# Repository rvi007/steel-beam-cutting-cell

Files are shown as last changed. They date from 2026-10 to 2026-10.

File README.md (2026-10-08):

# BEAM CELL

### Robotic cutting of UK structural steel

**Two robot arms on an overhead gantry (12 m or 20 m long) that cut beams to size: bolt holes, slots, notches,
mitres and cut-to-length. Drawings in, finished beams out.**

By **Ravi Mahadeva** · UK codes · runs on an NVIDIA Jetson Orin Nano · opens in any web browser

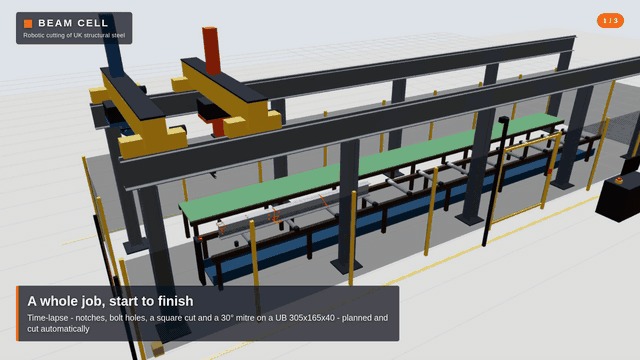
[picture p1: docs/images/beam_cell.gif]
BEAM CELL cutting a beam


▶ **[Watch the 30-second video](docs/video/beam_cell_30s.mp4)**

> 🤝 **Looking for collaborators and sponsors** - steel fabricators, engineers, robotics and automation
> people, and anyone who can help with parts, workshop space or test steel:
> **[get in touch](https://github.com/rvi007/steel-beam-cutting-cell/issues/new/choose)**.
> You're welcome to read everything here; using, building on or selling the code or the design needs
> written permission - see [LICENSE](LICENSE).

---

## What it does

Two robot "hands" hang from an overhead gantry above a 12-metre roller bed:

| | The **Cutter** (orange) | The **Handler** (blue) |
|---|---|---|
| Tool | plasma torch | electromagnet |
| Job | bolt holes, slots, openings, notches (copes), mitres, cut-to-length | holds each part while it is cut free, then carries it to the outfeed table |

You give it parts, as **NC1 files** from Tekla, Advance Steel or SDS2, or drawn on screen. It then:

1. **checks every part against the UK codes**, and tells you what is wrong and why,
2. **fits the parts onto stock bars** to waste as little steel as possible,
3. **plans every move of both arms** and checks they never collide,
4. **plays the whole job in 3D**, with a real safety system around it.

Or use **manual cut**: click on the beam to put a hole or a cut exactly there.

Everything in the 3D view is real CAD: the same solids are in the STEP files in `cad/`. There is
also a **1:10 desk-top prototype**, about £1,150 to build, with a shopping list and an assembly drawing.

## Start it

On the Jetson (or any Linux PC or Mac):

```
git clone https://github.com/rvi007/steel-beam-cutting-cell.git
cd steel-beam-cutting-cell
sudo apt install python3-numpy python3-opencv     # once; OpenCV is only needed for the camera
./start.sh
```

Then open **http://localhost:8080** in a web browser. From a phone, tablet or laptop on the same Wi-Fi,
use the address the terminal prints (for example `http://192.168.1.20:8080`).

**Every time after that:** `cd steel-beam-cutting-cell`, then `git pull` (to get the latest version), then `./start.sh`.

**Start it automatically when the Jetson boots:** see [docs/JETSON_SETUP.md](docs/JETSON_SETUP.md).

**Something not working?** Run `python3 -m beamcell.doctor`. It checks everything and tells you what to fix.

## A 5-minute tour

1. **Safety tab**: press **Reset**, tick the pre-start checklist and confirm. Like a real machine, nothing moves until you do.
2. **Machine tab**: example parts are already loaded. Press **Plan this bar**, then **Run**.
   Press **Follow Cutter** to watch the holes and notches being cut, and **Follow Handler** to watch a finished beam carried away.
   Point at anything in 3D to see what it is.
3. **Parts tab**: drag in NC1 files from Tekla, or pick *Add an example*. Every face is drawn,
   with its UK code checks. Click a part to edit it, for example to add a bolt group or a notch.
4. **Manual cut** (top left of the Machine tab): pick a section and a length, click on the beam to put a hole there,
   press **+ Cut** to cut it, then **Plan these cuts** and **Run**.
5. **E-STOP** (or the Esc key) while it runs: everything stops. Release it, press Reset, then Start to carry on.
6. When a job finishes, the **Job finished** window asks what next: next bar, run again or **Delete this job**.
   **Job history & saved jobs** (Machine tab) lists every job that ran, whether it ran **clean** or was stopped
   (each E-stop, gate or camera stop with its time), each with a **Delete** button.
7. **Prototype tab**: the 1:10 prototype in 3D. Every part is numbered, matching the shopping list. Click a part to see what it is and where to buy it.
8. **Camera tab**: start the camera and walk towards the machine. It slows down when you get close and stops when you get too close.
9. **Plasma tab**: plasma doesn't always cut the same, so try settings on a test piece, then save the ones that work, named after the beam.
   Next time that beam is cut, the Machine tab uses them automatically.
10. **Reports** (top right): every stop during a job saves a problem report. Add a note and press **Send to developer**.
11. **Machine size** (Machine tab): 12 m or 20 m long, 3 m wide. Stock bars up to 20 m; the 3D model, planning and checks follow.
12. **Bar check at Start**: after the safety checks, the Cutter measures the bar and checks it against the job (section, thicknesses,
   length, every hole, holes already in the bar). If it doesn't match, the job doesn't start and a window says why.
   Try it: Sensors tab, *Bar on the bed*, pick "a bar too short", then press Run. When the bar matches, a window shows the
   program next to what was measured on the cutting area (web and flange), then cutting starts.
13. **Power cut or stop in the middle of a job**: progress is saved to disk every second. When the app starts again a window
    says when, why and where it stopped and what is done. *Carry on* skips what is done, redoes the interrupted operation from
    its start, re-measures the bar and checks the cuts already made (scan back) before anything moves; a green arrow and a
    banner show where it restarts.
14. **Loading and unloading without entering the cell**: bars are put down by forklift / side loader (or beam dollies) on the
    infeed cross-transfer rack outside, and a driven infeed conveyor takes them in through the light-curtain opening. After a
    job the outfeed cross-transfer carries the finished parts out through the back fence (perimeter light grid with muting)
    onto a buffer rack beside a marked forklift aisle; short parts go in a stillage for the pallet truck.
15. **Sensors tab**: every sensor (two cameras, bar finding, torch, magnet, safety), the **bar check**, the **plasma settings**,
   and what each hand does for every stop. Press **Simulate** on "load slipping" or "object on the bed" and watch it react.

<details>
<summary><b>Camera not working?</b></summary>

1. Run `python3 -m beamcell.doctor`. The **Cameras** line lists every camera Linux can see and says what's wrong.
2. In the app's Camera tab, leave **Auto** selected, or pick the camera from the list.
3. Common fixes:
   - **No camera found at all:** plug the USB camera straight into the Jetson (not into an unpowered hub), or reseat the CSI ribbon cable (blue side towards the latch), then reboot.
   - **"not in the video group":** run `sudo usermod -aG video $USER`, then log out and back in.
   - **CSI ribbon camera:** it needs the Jetson's own OpenCV (`sudo apt install python3-opencv`), not `pip install opencv-python`. Test the camera with `nvgstcapture-1.0`.
   - **Camera busy:** close any other program that is using it (Cheese, a browser tab).
</details>

## Documents

| Read this | To learn about |
|---|---|
| [Safety](docs/SAFETY.md) | **stops, UK law and standards, risk assessment, E-stop wiring** |
| [Sensors](docs/SENSORS.md) | **the two cameras, how the beam is found and measured, what each hand does when something goes wrong, the standards** |
| [Plasma](docs/PLASMA.md) | how the torch finds the steel and holds its height; settings for each kind of cut |
| [How the machine works](docs/MACHINE.md) | the layout, how a bar is cut, and a map of the code |
| [UK codes](docs/UK_CODES.md) | every UK rule it checks, and where each one comes from |
| [NC1 files](docs/NC1_FILES.md) | getting parts out of Tekla: what is read, faces and coordinates |
| [Steel frame in Tekla](docs/TEKLA.md) | the cell's structural steelwork as IFC for Tekla: import, marks, cut list, what the engineer must design |
| [The 1:10 prototype](docs/PROTOTYPE.md) | **what to buy (about £1,150), how to build it, safety wiring** |
| [Shopping list (PDF)](docs/Prototype_Shopping_List.pdf) | every part with its price and a link to buy it, to print out |
| [Assembly drawing (PDF)](docs/Prototype_Assembly.pdf) | every part numbered and shown where it goes |
| [Jetson setup](docs/JETSON_SETUP.md) | running on the Orin: start at boot, full-screen mode, camera, YOLO, memory |
| [The AI advisor](docs/ASSISTANT.md) | "what's happening" in plain English, and the optional AI advisor |
| [A scale model](docs/SCALE_MODEL.md) | a static display model at 1:20 or 1:100 |
| [Jetson specs](docs/JETSON_SPECS.md) | the Orin's hardware and software |
| [How the code works](docs/HOW_IT_WORKS.md) | **a guided tour: which file does what, how the screen and the engine work together, the journey of a job** |
| [For developers](docs/DEVELOPMENT.md) | how the code fits together, and the rules for changing it |

## Honest limits

- **It is a simulation and a planner, not yet a machine controller.** It doesn't drive motors yet.
  The prototype guide explains what's needed for that.
- **Check NC1 files against their drawings.** The face conventions follow the DSTV standard as
  usually exported. Check one of your own Tekla parts against its drawing (see [NC1 files](docs/NC1_FILES.md)).
- **The safety functions are software.** They behave like a real safety system, but a real machine needs
  them in certified safety hardware, and a camera with AI is never a safety device on its own (see [Safety](docs/SAFETY.md)).
- **Section sizes come from published Blue Book data.** Check them against current mill data before real fabrication.

<details>
<summary><b>For developers: folders, tests, CAD and the video</b></summary>

### What's in each folder

```
steel-beam-cutting-cell/
├── start.sh              starts the app (./start.sh --camera 0 starts it with the camera on)
├── config/cell.toml      all the settings: safety, camera zones, GPIO wiring, AI advisor, port
├── beamcell/             the engine (Python)
│   ├── server.py         web server and the API the browser talks to
│   ├── safety.py         safety controller: E-stop, interlocks, modes, reset/start, watchdogs
│   ├── history.py        job history (jobs/history.json)
│   ├── plasma_presets.py saved plasma settings that worked (plasma_settings/)
│   ├── reports.py        problem reports for the developer after every stop (reports/)
│   ├── gpio_inputs.py    real E-stop / gate / light curtain / reset buttons on the Jetson's pins
│   ├── assistant.py      "what's happening" in plain English + the optional AI advisor
│   ├── doctor.py         system check: python3 -m beamcell.doctor
│   ├── sections.py       UK section library and exact cross-sections (data/uk_sections.json)
│   ├── uk_codes.py       UK code values: hole sizes, edge distances, grades
│   ├── parts.py          parts, notches, mitres, the code checks, nesting on bars
│   ├── nc1.py            reads and writes DSTV NC1 files
│   ├── arm.py, machine.py   the 6-axis arms and the cell's sizes
│   ├── planner.py        plans every move of both hands for a bar
│   ├── manual.py         manual cutting
│   ├── collisions.py     checks the arms never touch the steel
│   ├── cad.py            makes the CAD: STEP files and the 3D view's models (needs CadQuery)
│   └── vision.py         camera + YOLO person detection + safety zones
├── web/                  the app in the browser (index.html, css/, js/, models/, vendor/three.js)
├── cad/                  STEP files: the whole cell, the 1:10 prototype, every example part
├── examples/nc1/         example NC1 files of typical UK parts
├── docs/                 the documents above, images, video, PDFs
├── tools/                makes the example files, PDFs, assembly pictures and the video
├── deploy/               start-at-boot service for the Jetson
├── tests/                automatic tests (GitHub runs them on every push)
├── models/               put YOLO .onnx models here (see docs/JETSON_SETUP.md)
└── jobs/, logs/, plasma_settings/, reports/
                          your saved jobs, job history, safety log, plasma settings and problem reports (not in git)
```

### Tests

```
python3 -m unittest discover -s tests -t .     # about 1 minute
python3 tests/sweep_sections.py                # every UK section, about 4 minutes
```
GitHub runs the tests on every push: with the Orin's versions (Python 3.12, numpy 1.26.4,
OpenCV 4.6) and the latest ones, plus a browser test of the whole app and a CAD build.

### Make the CAD again (after changing the machine)

On a PC (CadQuery is big; the Jetson doesn't need it because the files are already in the repo):
```
pip install cadquery
python3 -m beamcell.cad                 # everything: parts, the cell, the prototype
python3 -m beamcell.cad parts my.nc1    # STEP solids of your own NC1 parts
```

### Make the video again

```
python3 -c "import beamcell.server as s; s.SAFETY.cfg['heartbeat_timeout_s'] = 600; s.main(['--port', '8099'])" &
node tools/make_video.mjs http://localhost:8099 docs/video/beam_cell_30s.mp4
```
</details>

## Author and licence

**Ravi Mahadeva**: design, development and the prototype.

© 2026 Ravi Mahadeva. All rights reserved. See [LICENSE](LICENSE). The UK section data comes
from the `steelsnakes` package (GPL-2.0), and three.js is MIT-licensed (`web/vendor/LICENSE-three.txt`).

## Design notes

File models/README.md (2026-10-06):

# YOLO models

Put `yolo11n.onnx` here, then build the GPU engine on the Jetson: `tools/make_trt_engine.sh`
(it makes `yolo11n.engine`). Pick "YOLO on the GPU" in the Camera tab.
See docs/JETSON_SETUP.md, "Person and object detection (YOLO) - on the GPU".
Model files aren't kept in git (size, and Ultralytics models are AGPL-3.0).

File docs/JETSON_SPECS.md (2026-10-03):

# Jetson specs (the user's local machine)

Read from the board on 2026-10-03. This is where the Arduino, servo, knob and 3D
windows run. Cloud sessions can't reach it, so write code that fits these limits.

## Hardware
| Part | Spec |
|---|---|
| Board | NVIDIA Jetson Orin Nano Developer Kit **Super** |
| CPU | 6-core Arm Cortex-A78AE, up to 1.73 GHz (aarch64) |
| GPU | NVIDIA Ampere, up to 1.02 GHz in Super mode |
| RAM | **4 GB** (3.4 GB usable), shared by CPU and GPU |
| Swap | 1.7 GB zram (compressed RAM) |
| Power mode | `MAXN_SUPER` (fastest) |

The 3.4 GB of usable RAM points to the 4 GB Orin Nano. NVIDIA's spec sheet for that
model lists 512 CUDA cores, 16 tensor cores and about 34 TOPS in Super mode
(spec-sheet figures, not measured on this board).

## Storage
| Item | Detail |
|---|---|
| Drive | 256 GB NVMe SSD, EDILOCA EN605 (238.5 GB usable) |
| Root `/` | `nvme0n1p1`, ext4, 233 GB: **30 GB used, 191 GB free (14%)** |
| `/boot/efi` | `nvme0n1p10`, vfat, 63 MB |
| Other partitions | 13 small NVIDIA boot/firmware partitions (under 0.5 GB each), no filesystem mounted |
| Space use | `/usr` 21 GB, `/opt` 4.5 GB, `/home/ravi` 2.8 GB, `/var` 1.5 GB |
| SD card | None |

## Software
| Item | Version |
|---|---|
| JetPack | 7.2.1 (Jetson Linux R39.2.1) |
| OS | Ubuntu 24.04.4 LTS, kernel 6.8.12-tegra |
| CUDA | 13.2 |
| TensorRT | 10.16 |
| Python | 3.12.3 |
| Python libs | numpy 1.26.4, matplotlib 3.6.3 (TkAgg), scipy 1.11.4, OpenCV 4.6.0, pyserial 3.5 |
| PyTorch | Not installed |
| arduino-cli | `~/.local/bin/arduino-cli`, board `arduino:avr:uno` |

## Connections
- Internet: Wi-Fi through a phone hotspot (`172.20.10.x`). **Avoid big downloads.**
- Ethernet: not connected.
- Arduino UNO: USB on `/dev/ttyACM0` (group `dialout`).

## Limits to design around
- **Memory is very tight.** When checked, only about 365 MB of RAM was free and the
  1.7 GB swap was full, with the desktop and a 3D window open. Run one GUI program at a
  time and keep scripts light: no big arrays, no heavy plotting loops.
- Only numpy, matplotlib, scipy, OpenCV and pyserial are available. Don't add
  dependencies that need `pip install`.
- matplotlib 3D redraws are the slowest part. The control loops run at about 20 Hz
  (`plt.pause(0.05)`), so don't add work that slows them down.

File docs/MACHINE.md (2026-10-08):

# The machine and how a job runs

## Layout

```
   Y (width 3 m)            safety fence all round, gate + light curtain at the front
   ^      runway beams (UB on UC columns), rails at 3.4 m
   |  ==================================================================
   |   outfeed table (green)    y = +0.85   finished parts are put down on it
   |
   |   stock bar on rollers     y = -0.50   up to 12 m, rollers every 1 m, scrap tray underneath
   |  ==================================================================
   +----------------------------------------------------------------------> X (12 m)
        HANDLER bridge (blue) ->                     <- CUTTER bridge (orange)
        parks at x = -1.1                                parks at x = 13.1
```

| | Cutter (orange) | Handler (blue) |
|---|---|---|
| Job | plasma torch: holes, slots, openings, notches, end cuts, cut-off | magnet: holds each part while it's cut free, puts it on the outfeed table |
| Gantry axes | X bridge 1.0 m/s, Y carriage 0.8 m/s, Z column 0.5 m/s | same |
| Arm | 6 axes, UR5 geometry (upper arm 425 mm), hung upside down | 6 axes, 1.3x bigger |
| Tool | 400 mm plasma torch (long, to reach under wide flanges) | magnet pad, 500 kg |
| Total | 9 axes | 9 axes |

Both bridges share the rails: the Handler works on the low-X side, the Cutter on the high-X
side, and the planner keeps them at least **1 m** apart at every moment. Both arms work
**elbow up** (like real ceiling-mounted robots): the whole arm stays above the tool tip.

## How sections lie on the bed

| Section | Lies | Torch passes for a cut |
|---|---|---|
| UB / UC / UBP | web upright, centred | top flange straight down; web from the +Y side (between the flanges); bottom flange with the torch tilted 45° from each side of the web |
| PFC | web upright on the +Y side, flanges pointing -Y | top flange down; web from outside; bottom flange tilted 45° from the open side |
| Angles | longer leg upright on the +Y side, other leg flat | upright leg from the side; heel corner tilted 45°; flat leg straight down |
| Hollow | not cut (needs a chuck) | - |

Holes are cut straight through their plate: top flange from above, web from the side, the
flat leg of an angle from above. Bottom-flange holes on I sections and channels can't be
reached.

## How a bar is cut

1. Parts are **nested** on the bar: 10 mm trimmed off the rough mill end, then part after
   part. Two square ends share one cut; a notched or mitred end gets a 20 mm gap.
2. For each part, from X = 0 upwards:
   1. the start cut, unless it shares the previous part's cut-off - the offcut falls between the
      rollers into the scrap tray;
   2. holes, slots and openings **in order along the bar**, one bolt group at a time, top hole
      first - never jumping back and forth;
   3. the Cutter goes to the cut-off and waits; the **Handler** comes in and puts its magnet on the part;
   4. the cut-off, face by face;
   5. the Handler lifts the part 250 mm, carries it to the outfeed table and puts it down,
      while the Cutter starts on the next part.
3. A last part that reaches the end of the bar needs no cut-off: the Cutter moves out of the
   way and the Handler takes it. Anything left over is the remnant and stays on the bed.

**Gravity:** nothing floats. The bar rests on rollers (every 1 m, top at 0.9 m). A loose piece
stays on the bed only if it spans two rollers - otherwise it would tip, so short offcuts and a
short remnant fall (time from g = 9.81 m/s²) into the scrap tray, and short, tall slices tip over
flat. Carried parts are put down exactly on the outfeed table. `tests/test_planner.py` checks it.

**Holes are where the drawing says.** The planner never moves a hole: x and y come from the NC1
file or the part editor. New bolt groups in the editor (and the example files) sit on the
centre line of the web that's left (below any notch); a **centre** button puts any hole there.

## Manual cutting

Machine tab, **Manual cut**: pick a section and bar length, then add holes, cuts (square or
mitred in the web) and notches - or click on the web / top flange in the 3D view. The cuts
split the bar into pieces: each piece is carried to the outfeed table, pieces under 150 mm fall
into the scrap tray, the rest stays on the rollers. Same UK checks, same planner and collision
check, same safety rules (`beamcell/manual.py`).

Long cuts (over 150 mm - webs of deep beams, flanges) move the gantry with the torch, as a
real machine's coordinated axes do; short ones (holes) use the arm alone.

## Safety, by construction and by checking

- **Bridges**: a move that would bring them within 1 m waits for the other hand, or makes it back off.
- **Travel**: long moves lift the column to 3.0 m, travel, then come down.
- **Torch approach**: the torch comes in and leaves along its own axis, from a point outside the section.
- **Collision check** (`beamcell/collisions.py`): the whole plan is replayed every 0.4 s and every
  arm link and tool is checked against the steel (each plate following its real outline, so
  notches count; offcuts until they drop; carried parts where they are) and the bed.
- **Safety controller** (`beamcell/safety.py`): E-stop, gate, light curtain, extraction, camera
  zones, modes, watchdogs - every stop latches; Reset then Start (see `SAFETY.md`).

`tests/sweep_sections.py` plans a typical part on **every one of the 267 cuttable UK
sections** (from a 20x20 angle to UB 1016x305x584) and checks all of the above: 0 problems.

## Timing

Plasma speeds follow typical 130 A values: 50 mm/s up to 6 mm thick down to 10 mm/s over
20 mm; tilted cuts count as 1.4x the thickness. Each pierce takes 0.6 s. A typical bar of two
5.2 m notched secondary beams takes about 7.5 minutes.

## Code map

| File | What it does |
|---|---|
| `beamcell/sections.py` | UK section library, exact outlines with radii, plates and DSTV faces |
| `beamcell/uk_codes.py` | BS EN 1090-2 / BS EN 1993-1-8 / SCI values |
| `beamcell/parts.py` | parts, face outlines (notches, mitres), cut chains, UK checks, nesting onto bars |
| `beamcell/nc1.py` | reads and writes DSTV NC1 files |
| `beamcell/arm.py` | 6-axis arm kinematics, IK for any tool direction |
| `beamcell/machine.py` | the cell's sizes, the two hands, comfortable elbow-up poses |
| `beamcell/planner.py` | turns a bar into timed tracks for both hands, and where loose pieces fall |
| `beamcell/manual.py` | manual cutting: the operator's cuts become pieces and a plan |
| `beamcell/cad.py` | the CAD model: STEP files and `web/models/*.glb` (CadQuery, on a PC) |
| `beamcell/collisions.py` | replays a plan and checks arms against the steel |
| `beamcell/vision.py` | camera, YOLO / HOG person detection, warning + danger zones |
| `beamcell/safety.py` | safety controller: E-stop, interlocks, modes, reset/start, watchdogs, ISO 13855 distance |
| `beamcell/gpio_inputs.py` | optional wired E-stop / gate / curtain / reset on the Jetson's pins (fail-safe) |
| `beamcell/assistant.py` | plain-English situation + optional AI advisor |
| `beamcell/doctor.py` | system check and setup plan |
| `beamcell/config.py` | reads `config/cell.toml` |
| `beamcell/server.py` | web server and JSON API |
| `web/js/scene.js` | the 3D cell: loads the CAD model (GLB) and poses the moving bodies with the kinematics; hover labels |
| `web/js/manual.js` | the Manual cut panel, markers and clicking on the steel |
| `web/js/geometry.js` | steel parts plate by plate, with real holes and notches |
| `web/js/app.js` | playback of the plan, the Machine tab |
| `web/js/parts.js` | Parts tab: NC1 import, editor, drawing, checks |
| `web/js/library.js` | Section library and STL export |
| `web/js/camera.js` | Camera tab |

## Next steps (ideas)

1. Read real NC1 files from your Tekla models and compare the drawings (see `NC1_FILES.md`).
2. Train a YOLO model to see the **beam** (its end and position) so the Cutter corrects for
   where the bar really lies.
3. Bevel cuts for weld preparation (the torch is already 6-axis).
4. Drive a 1:10 model's motors from the plan (see `SCALE_MODEL.md`).
5. Two-hand lifting for parts over 500 kg.

## Loading and unloading (material flow)

Nobody walks into the cell to load or unload it. Steel moves in and out on conveyors, and people and forklifts work outside the guard:

| Where | What | Who / what moves it |
|---|---|---|
| **Infeed rack** (outside, infeed end) | chain cross-transfer arms every 2.5 m at bed height; a stop lets one bar at a time onto the conveyor | forklift with a side loader, an overhead crane, or a pallet truck with beam dollies, in the marked loading aisle |
| **Infeed conveyor** (outside, in line with the bed) | driven 101.6 mm rollers every 1 m, chain guard, gearmotor; bridging rollers through the light-curtain opening | the machine: drives the bar in; the pop-up end stop drops while it comes in, then rises and the bar is datumed against it |
| **Outfeed cross-transfer** (inside to outside, back) | chain arms every 1 m (a short part always sits on two), line shaft and gearmotor | the machine, after each job, only when the cell is clear (safety PLC) |
| **Back opening** | perimeter light grid, 4 beams (SICK deTem4 class, Type 4), muting sensors and lamp | lets steel on the transfer through, stops the machine for a person (BS EN IEC 62046, BS EN ISO 13855) |
| **Buffer rack** (outside, back) | the arms continue 1.7 m outside the fence onto legs, with end stops | forklift / side loader picks the parts from the marked unloading aisle |
| **Pallet-truck bay** | stillage on a Euro pallet for short parts and offcuts | hand pallet truck |

A hand pallet truck is right for stillages, not for long beams: a 6-12 m beam needs a side loader, a crane, or two beam
dollies. Aisles are 3.5 m wide and marked (HSG136 workplace transport).

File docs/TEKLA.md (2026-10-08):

# The steel frame in Tekla Structures

This is for the steel detailer. The cell's fabricated structural steelwork is exported as an IFC model
you can bring into Tekla, convert to native parts, connect up, and get drawings and NC1 files from.

| File | What |
|---|---|
| `cad/beam_cell_steel_12m.ifc` | the 12 m machine's frame (IFC2X3, millimetres) |
| `cad/beam_cell_steel_20m.ifc` | the 20 m machine's frame |
| `cad/beam_cell_steel_12m.csv`, `_20m.csv` | cut lists: every mark, then totals by profile, then the grand total |

Made by `python3 -m beamcell.ifc_export` (code in `beamcell/ifc_export.py`, checks in `tests/test_ifc.py`).
Run it again after any change to the machine's sizes in `beamcell/machine.py`.

## Importing into Tekla

The file is **IFC2X3** (Coordination View 2.0 style), which Tekla imports most reliably. There are two ways in.

**1. As a reference model, then convert (recommended).**
1. *Manage > Reference model* (older versions: *File > Insert reference model*), pick the .ifc, insert at 0,0,0, scale 1.
2. Select the reference objects, right-click *Convert IFC objects* (or *Manage > Convert IFC objects*).
3. Tekla makes real beams, columns and plates with the profile, material and position from the file. Check
   the conversion log for anything left as a "brep" - there should be nothing; every member is a simple extrusion.

**2. File > Import > IFC** (older versions and some environments). It makes Tekla parts straight away.
Use this if you don't want a reference model hanging about.

**Profile and material mapping.** Each member's profile name is already in the Tekla UK catalogue format:
`UB457*191*67`, `UC254*254*73`, `RHS120*80*5`, `RHS100*80*5`, `SHS80*80*5`, `SHS100*100*6.3`, `L70*70*7`,
`PL25*500`, `PL20*300`, `FL60*50`, `FL60*30`. It's in three places: the profile (`ProfileName`), the element's
`ObjectType`/`Description`, and the property set. If your environment names something differently (e.g. `EA70*70*7`
rather than `L70*70*7`), add a line to the conversion's profile mapping file (`ProfileConversion.cnv` /
*IFC object conversion > Profile mapping*) rather than editing the model. The material is `S355` throughout: map
it to S355J2 (or S355J2H for the hollow sections) in the material mapping if your catalogue wants the sub-grade.

After converting, run *Clash check* against your connections and *Numbering* - Tekla will renumber; the marks
below are only for referring back to this model and the cut list.

## Coordinates

- Origin: the **bar datum** - the face of the bar end stop on the bed's centre line, at finished floor level.
- **X** along the bed, infeed end towards outfeed end. **Y** across: the front runway is at Y = -1500, the back at Y = +1500.
  **Z** up from finished floor level (top of slab = 0).
- Millimetres. Every position and length is rounded to 1 mm.

## What's in the model

Each member is an `IfcBeam`, `IfcColumn`, `IfcPlate` or `IfcMember` with `Name` = mark, and a property set
`Pset_BeamCellSteel` with **Mark, Assembly, Profile, Grade, Length, Weight** and, where useful, **Notes**
(holes, splices, fixings). Members are grouped by `IfcElementAssembly` per assembly below.

| Assembly | Marks | Members |
|---|---|---|
| RUNWAY-FRONT / RUNWAY-BACK | RB, R | Runway beams UB 457x191x67, underside at Z 2850, running 300 mm past the end columns. Crane rail 60x50 flat (FL60*50) on top, top at Z 3353.4. |
| COLUMNS-FRONT / COLUMNS-BACK | C, BP, CP | Columns UC 254x254x73 (web along X) at no more than 4 m centres, Z 25 to 2830. Base plates PL25 500x500 under each, cap plates PL20 300x300 on top. |
| BRACING-FRONT / BRACING-BACK | BX | X-bracing, two L70x70x7 diagonals in the first bay at the infeed end, in the plane of the columns, passing either side of a centre gusset. |
| TRAY-FRONT / TRAY-BACK | TB | Energy-chain tray brackets, 60x30 flat, under the runway, sticking out 350 mm outboard. |
| BED | BR, BL | Roller bed side rails RHS 120x80x5 (Y -900 and -100, top at Z 810), legs SHS 80x80x5 every 2 m. |
| OUTFEED | OF, OL | Outfeed table rails RHS 100x80x5 (100 high, top at Z 870), legs SHS 80x80x5 every 2 m. |
| END-STOP | ES, ESP | Bar end stop post SHS 100x100x6.3 on a PL20 300x300 base plate, top at Z 880. |

**Things I've added so a fabricator can make it** (they are not in the 3D view of the machine):
- Cap plates PL20 300x300 on every column; the runway's bottom flange bolts to them. Columns are shortened by 20 mm to suit.
- Base plates carry a note: 4 holes 26 dia for M24 holding-down bolts at 380 centres, 25-40 mm grout. The holes are data only - not cut in the model.
- **Runway splice (20 m machine only).** The runway is 23.2 m long, too long for stock, so it's in two 11.6 m lengths spliced over the column at X 10000. The crane rail is split at the same place - stagger the rail joint from the beam joint if you can (500 mm or more). The 12 m machine's runway is one 15.2 m length.
- Bed and outfeed rails are in two equal lengths (hollow stock is 12 m), joined over a leg.
- Longitudinal X-bracing in one bay a side.

## What is NOT designed - needs a structural engineer

- **Connections**: splices, cap plate bolts, bracing gussets, bed and leg feet - all yours to design and detail (to BS EN 1993-1-8 / the engineer's forces).
- **End-frame (cross-wise) stability.** There is no cross-tie between the two runway lines, on purpose: the bridges run on top of the runways and the masts and arms hang down to bed level, so any steel between the runways would be in their way. The machine's moving envelope is X from the rail end -0.5 m to the other end +0.5 m, Y -1250 to +1250, Z 900 to 4100 - **no steel may go in that box**. Cross-wise stability must come from moment-fixed column bases, or from ties above Z 4100, or from steel outside the fence. The structural engineer decides.
- **Crane loads**: the bridges' wheel loads, surge and braking forces, and the runway's deflection limits (span/600 or tighter for rail alignment) - the engineer checks the UB 457x191x67 and the columns.
- **Foundations** and holding-down bolts (sizes above are only a starting point).
- **Rail fixing**: shown as a flat bar on the top flange. Clips or continuous welding, and rail tolerances, are the engineer's and the crane supplier's call.

Bought-in items (the grating deck, rollers and bearings, the datum block and laser on the end stop, the fence, the energy chains and their trays) are not in the model.

## Cut list totals

Weights are plain section weight x length (plates: area x thickness x 7850 kg/m3). Bolts, welds, gussets and connection plates are **not** included - allow 5-10 % more.

| Profile | 12 m: qty | 12 m: length (m) | 12 m: kg | 20 m: qty | 20 m: length (m) | 20 m: kg |
|---|---|---|---|---|---|---|
| UB457*191*67 | 2 | 30.4 | 2040 | 4 | 46.4 | 3114 |
| UC254*254*73 | 10 | 28.1 | 2050 | 14 | 39.3 | 2870 |
| FL60*50 (crane rail) | 2 | 30.4 | 716 | 4 | 46.4 | 1093 |
| PL25*500 (base plates) | 10 | - | 491 | 14 | - | 687 |
| PL20*300 (cap plates + end stop base) | 11 | - | 155 | 15 | - | 212 |
| L70*70*7 | 4 | 16.5 | 122 | 4 | 16.9 | 125 |
| RHS120*80*5 | 4 | 25.2 | 370 | 4 | 41.2 | 606 |
| RHS100*80*5 | 4 | 25.2 | 322 | 4 | 41.2 | 527 |
| SHS80*80*5 | 28 | 20.4 | 237 | 44 | 32.1 | 372 |
| SHS100*100*6.3 | 1 | 0.9 | 16 | 1 | 0.9 | 16 |
| FL60*30 (tray brackets) | 8 | 4.2 | 60 | 12 | 6.4 | 90 |
| **Total** | **84 members** | | **6,579 kg** | **120 members** | | **9,710 kg** |

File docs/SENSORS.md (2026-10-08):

# Sensors: finding the beam, watching the cell, and what the hands decide

The cell has two cameras and a set of sensors. On the prototype most of them are **placeholders**:
the software already has a place for each one and **simulates** it, so the planner, the safety
controller and the screens work today. When a sensor is wired in, it replaces the simulation.
All of them are listed on the **Sensors** tab, with what each does, where it goes and what to buy.

## 1. How a beam is found and measured (what happens in real life)

A rolled steel beam is never exactly its catalogue size, and never exactly where the crane put it:

- **BS EN 10034** lets an I or H section be a few mm deeper or wider than its catalogue size, slightly out of square,
  and bowed by up to 0.1-0.3 % of its length. That is **18 mm over 12 m** for a UB 305.
- The crane puts the bar down **somewhere near** the end stop, not exactly at x = 0.

A cut that is 10 mm out is a scrapped part, so every production line **measures first, then cuts**:

| Step | What happens | Sensor | On the prototype |
|---|---|---|---|
| 1. Is there a bar? | A light beam across the bed is broken by the bar | **Bar-present photo-eye** | IR break-beam pair |
| 2. Where does it start? | A laser on the end stop measures the distance to the bar's end. That distance is the **x offset** every cut moves by | **Datum laser** | VL53L1X time-of-flight sensor |
| 3. What shape is it really? | The Cutter runs along the bar with a **laser profile scanner** and the **torch camera**: real depth, flange width, web and flange thickness, out-of-square, bow, where the far end is, and any holes already in the bar | **Profile scanner + torch camera + gantry encoders** | Camera 2 + a line laser |
| 4. Where is the surface, right here? | Before every cut the torch touches the steel (**ohmic touch-off**). That is the true surface, so the cut height is right | **Torch touch-off** | Micro-switch on the sprung pen holder |
| 5. Check | Every reading is compared with the BS EN 10034 tolerances. Out of tolerance means the machine doesn't start (wrong section, bent bar, bar not seated) | - | the same check, in software |

The result is the **bar check**. It appears under every plan on the Machine tab, and you can try it
on the Sensors tab. Today its readings are simulated: small, realistic and repeatable.

### The bar check at Start: does this bar fit THIS job?

When you press **Start**, and only once the safety checks have passed (Reset, checklist, gate,
extraction), the Cutter measures the bar and checks it against the job before it cuts anything.
In the 3D view it measures in two passes, each with a red fan of laser light (the profile scanner):
first along the **top flange**, torch down (depth, flange width and thickness, bow, length), then along
the **web** from the side (web thickness and height, holes already in it). Web and flange together tell
which section the bar really is - the message names it. When it gets to the start, a message gives what
it measured (length, depth, flange, web, holes found):

| Check | Fails when |
|---|---|
| Section | depth, flange width, web or flange thickness is outside BS EN 10034 (usually the wrong section) |
| Straightness | out of square or bowed more than BS EN 10034 allows |
| Length | the bar is shorter than the job needs (up to its last cut) |
| Holes on the real steel | a hole would break a UK rule (edge, end distance, root radius) on the bar as measured, even though it passes on the drawing: the steel is at the edge of its tolerance |
| Holes already in the bar | the torch camera finds a hole that isn't in the job where a part will be (a used bar or offcut) |
| A bar at all | the bar-present photo-eye sees nothing |

If anything fails, **the job doesn't start**. A window lists each problem and what to do. Fix the bar
(or the job), then press **Measure again and start**. A bar that passes isn't measured again when you
pause and carry on; a new plan, a new run or a new bar is measured again.

To try it without real steel, the Sensors tab has **Bar on the bed (simulation)**: put a short,
bent, wrong, narrow or thin bar, or one with a hole already in it, on the bed, then press Start.

### How the big suppliers do it

| Machine | How it measures the beam |
|---|---|
| **Ficep NOZOMI** (robotic plasma coping) | a **non-contact laser scanner** on the robot surveys the real profile in seconds, so the torch doesn't have to probe every start point |
| **Voortman V808** (robotic thermal cutting) | a **measuring sensor on the torch nozzle** measures the exact profile; the difference from the theoretical size is compensated during cutting; roller-feed measuring and clamping |
| **Lincoln Electric PythonX STRUCTURAL** | a **measuring stand** measures the exact length of the beam at the start; guaranteed accuracy of 1 mm over 12 m |
| **Hypertherm** torch height controllers (used on most plasma machines) | **initial height sensing by ohmic contact** (or stall detection), then **arc-voltage** height control during the cut |

BEAM CELL follows the same pattern: a laser scanner on the Cutter (like Ficep), touch-off at the
torch (like Voortman and every plasma height controller), and a datum and length check (like PythonX).

## 2. The two cameras

| | Camera 1: cell overview | Camera 2: close-up on the torch |
|---|---|---|
| Where | high on the infeed-end column, looking down the cell | on the Cutter, beside the torch, behind a spatter shield |
| Sees | **people** in the warning and danger zones (YOLO); **objects** left on the bed; a part **hanging or slipping**; offcuts stuck in the rollers; smoke | the **bar edge** and the real cut line; the kerf and **hole quality**; **nozzle wear**; the pen mark on the prototype |
| Prototype | USB wide-angle (P29) | Arducam IMX219 (P30) + line laser (P53) |
| Full size | IP67 industrial camera | welding camera with auto-darkening |

**A camera with AI is never the safety device.** Detecting people for *safety* needs certified
protective equipment: light curtains (BS EN IEC 61496-2), safety laser scanners, or a *certified*
vision-based protective device (IEC TS 61496-4-2 / 4-3). In this cell the cameras are an **extra**
layer on top of those: they can slow the machine down or stop it, but nothing relies on them alone.

## 3. Hazards: what is detected, and what each hand decides

Every stop has a **fixed decision**: what the Cutter does, what the Handler does, and what you
must do. The rules are written in advance and checked in the risk assessment; **an AI never
decides them on the spot**. The AI advisor can only explain what happened. The same table is on
the Sensors tab, and you can **simulate** the new hazards there and on the Safety tab.

| Hazard | Detected by | Stop | Cutter | Handler | You |
|---|---|---|---|---|---|
| Emergency stop | E-stop buttons | 0 | torch off at once; stops dead | stops dead; **magnet stays on** (battery backup) | find the cause, release, Reset, Start |
| Gate opened / light curtain | interlock, light curtain | 1 | torch off; controlled stop | stops; keeps holding its part | leave the cell, close the gate, Reset |
| Person in the danger zone | camera 1 / area scanner | 1 | torch off; controlled stop | stops; **never lowers a load towards a person** | everyone out, Reset |
| **Object on the bed** in the hands' path | camera 1 (object detection) | 2 | torch off; **holds where it is**; won't move into that area | holds; won't set a part down on it | remove the object, Reset |
| **Load slipping / wrong weight** | magnet current, load cell, camera 1 | 2 | stops | stops moving sideways at once; **magnet stays on**; if the floor and bed below are clear, **lowers the part slowly straight down** onto the bed or table, otherwise holds it and sounds the alarm | keep everyone from under the load; check magnet, weight, that it was cut free; Reset |
| **Torch collision** | breakaway switch | 1 | torch off at once; stops; lifts 50 mm | stops; keeps holding | check torch and nozzle, re-seat the mount, re-measure the bar, Reset |
| **Fire / smoke** | flame / smoke detector, camera 1 | 1 | torch off at once; stops and lifts clear | stops; keeps holding | fire procedure; extraction keeps running; Reset only when it's out |
| Fume extraction off | airflow switch | 1 | torch off at once | stops | get extraction running, Reset |
| Screen / camera / wiring fault | watchdogs | 1 | torch off; stops | stops; keeps holding | fix it, Reset |

**Stop categories** (BS EN 60204-1): **0** means the power is cut at once. **1** means a controlled
stop, then the power goes off. **2** means a controlled stop with the power kept on, so the hands
hold their position and the magnet keeps its grip. Category 2 is used for an object on the bed and
a slipping load, because cutting the power then would drop the load or let the arm sag.

Two rules run through all of these:

- **The magnet never lets go on a stop.** It follows BS EN 13155 (lifting magnets need a backup so a power failure doesn't drop the load) and LOLER.
- **Nothing moves over a person.** The Handler only lowers a load if the area under it is clear.

## 4. Standards that apply

| Standard | What it covers here |
|---|---|
| **BS EN ISO 17916** | safety of thermal cutting machines (gantry plasma machines) - the machine standard for this cell |
| BS EN ISO 12100 | risk assessment |
| BS EN ISO 13849-1 | safety-related control systems (performance level) |
| BS EN 60204-1 | electrical equipment; stop categories 0, 1, 2 |
| BS EN ISO 13850 | emergency stop |
| BS EN ISO 13855 | where to put a light curtain or scanner (safety distance) |
| BS EN ISO 14119 / 14120 | gate interlocks / guards |
| BS EN IEC 61496 (-2, -3, TS -4) | light curtains, laser scanners, vision-based protective devices |
| BS EN ISO 10218-1/-2 | the robot arms |
| **BS EN 13155** + LOLER | the lifting magnet: backup if the power fails, safety factor |
| **BS EN 10034** | rolling tolerances of I and H sections (the bar check) |
| **BS EN ISO 9013** | thermal cut quality (squareness, roughness) |
| **BS EN 1090-2** | execution of steel structures: thermal cutting and holes must meet the cut-quality and hardness requirements |
| COSHH + HSG258 | fume extraction (LEV) |
| Regulatory Reform (Fire Safety) Order 2005 | fire risk |
| PUWER 1998 | the machine as work equipment |

## 5. Wiring a sensor in

1. Fit it and wire it as the Sensors tab says (I2C, GPIO, USB...).
2. Safety devices (E-stops, gate, light curtain, scanner, torch breakaway) go to the **safety relay**,
   and an auxiliary contact goes to the Jetson's GPIO (see `docs/SAFETY.md`, wiring).
3. Process sensors (datum, scanner, load cell, current, flame) feed the software. Their reading
   replaces the simulation in `beamcell/sensors.py`. Set `[sensors] simulate = false` in
   `config/cell.toml` when all of them are real.
4. The second camera: `[sensors] torch_camera = "csi"` (or "0" / "1" for USB).

Sources for the supplier and standard details above: Voortman V808 product page, Ficep NOZOMI
601 RAZ, Lincoln Electric PythonX, Hypertherm (torch height control, True Hole), BSI (EN ISO 17916),
HSE (magnetic lifting devices), the Blue Book (BS EN 10034 tolerances).

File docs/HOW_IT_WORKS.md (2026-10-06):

# How the code works - a guided tour

This page explains how BEAM CELL is put together: which file does what, how the screen talks to the
engine, and what happens, step by step, from an NC1 file to a cut beam. Read it top to bottom once;
afterwards use it as a map.

## 1. The big picture: two programs that talk to each other

BEAM CELL is **two programs**:

| | The **engine** (Python) | The **screen** (JavaScript, in a web browser) |
|---|---|---|
| Folder | `beamcell/` | `web/` |
| Runs on | the Jetson | any browser: on the Jetson, a laptop, a tablet |
| Does | all the thinking: UK checks, nesting, planning, **safety decisions**, sensors, saving jobs | everything you see: tabs, buttons, the 3D view, playing the job |
| Master file | **`beamcell/server.py`** | **`web/js/app.js`** (loaded by `web/index.html`) |

They talk over **HTTP**, the same way a website talks to its server: the screen asks
(`GET /api/info`, `POST /api/plan` ...), the engine answers with **JSON** (plain data).

```mermaid
flowchart LR
    U([You]) --> B["Browser<br/>web/index.html + web/js/*.js<br/>(the screen)"]
    B -- "requests: /api/..." --> S["beamcell/server.py<br/>(the engine's front door)"]
    S -- "answers: JSON" --> B
    S --> P["planning<br/>parts.py · nc1.py · planner.py<br/>arm.py · collisions.py · plasma.py"]
    S --> SF["safety.py<br/>the one place that decides<br/>if the machine may move"]
    SF --- V["vision.py (camera)"]
    SF --- G["gpio_inputs.py (real E-stop, gate...)"]
    S --> D[("files: config/cell.toml<br/>jobs/ · logs/ · cad/ · web/models/")]
```

### The "main" files

- **`start.sh`** - what you run. It only does one thing: `python3 -m beamcell.server`.
- **`beamcell/server.py`** - **the master file of the engine.** `main()` at the bottom reads the
  settings, starts the safety watchdog, the camera and GPIO, then starts the web server. Every
  `/api/...` request arrives in its `Handler` class and is passed to the right module.
- **`web/index.html`** - the page: every tab, button and box, as HTML.
- **`web/js/app.js`** - **the master file of the screen.** Its `start()` function loads the data,
  builds the 3D view and switches on every tab; its `frame()` loop draws the machine 60 times a second.

## 2. Starting up: what happens when you type `./start.sh`

```mermaid
sequenceDiagram
    participant You
    participant start.sh
    participant server as server.py
    participant safety as safety.py
    participant browser as Browser (app.js)
    You->>start.sh: ./start.sh
    start.sh->>server: python3 -m beamcell.server
    server->>server: read config/cell.toml (config.py)
    server->>safety: create SafetyController, start 10 Hz watchdog
    server->>server: camera (vision.py), GPIO (gpio_inputs.py)
    server-->>You: "running: http://localhost:8080"
    You->>browser: open http://localhost:8080
    browser->>server: GET / (index.html, css, js, 3D models)
    browser->>server: GET /api/info, /api/sections
    browser->>browser: build the 3D cell (scene.js + web/models/*.glb)
    browser->>server: every 200 ms: POST /api/safety/tick ("I'm alive")
```

The **tick** every 200 ms matters: if the screen stops answering (crashed, network lost), the
safety controller's **watchdog** stops the machine within 2 seconds.

## 3. The journey of a job: from an NC1 file to a cut beam

```mermaid
flowchart TD
    A["1 NC1 file from Tekla"] -->|"POST /api/nc1"| B["nc1.py reads it<br/>parts.py makes a Part<br/>uk_codes.py checks it"]
    B --> C["Parts tab<br/>(parts.js) shows it + the checks"]
    C -->|"POST /api/nest"| D["parts.py nest_all()<br/>fits parts on 12 m bars"]
    D --> E["Machine tab: the bars<br/>(app.js renderBars)"]
    E -->|"Plan this bar: POST /api/plan"| F["planner.py Plan.build()<br/>every move of both arms"]
    F --> F1["arm.py: joint angles (IK)"]
    F --> F2["plasma.py: speed, pierce, height per cut"]
    F --> F3["collisions.py: arms never hit the steel"]
    F --> F4["sensors.py: the bar check"]
    F --> G["the plan (JSON): tracks, cuts, steps"]
    G --> H["app.js loadPlan(): builds the steel in 3D<br/>tells safety.py which job is loaded"]
    H --> I{"Safety tab:<br/>Reset + checklist + Start"}
    I -->|"safety.py says may_move"| J["frame() plays the job:<br/>arms move (kinematics.js), kerfs glow,<br/>parts are carried, offcuts fall"]
    J --> K["end reached: POST /api/safety/finished<br/>history.py records it"]
    K --> L["Job finished window:<br/>bar's parts leave the job, next bar..."]
```

Step by step, with the file that does each part:

| # | What happens | Screen (browser) | Engine (Python) |
|---|---|---|---|
| 1 | You drop an NC1 file | `parts.js` `importFiles()` | `nc1.py` `read()` → `parts.py` `Part` |
| 2 | Each part is checked against the UK rules | the ✓ / ✗ in the part list | `parts.py` `Part.check()` using `uk_codes.py` |
| 3 | Parts are fitted onto stock bars | Machine tab, "Bars" | `parts.py` `nest_all()` |
| 4 | You press **Plan this bar** | `app.js` `planBar()` | `server.py` `plan_bar()` → `planner.py` `Plan(bar).build()` |
| 5 | The planner works out every move | - | `planner.py` (order of cuts, approaches, the Handler's lift and carry) + `arm.py` (joint angles) + `plasma.py` (speeds) + `collisions.py` |
| 6 | The plan comes back and is drawn | `app.js` `loadPlan()`, `geometry.js` (the steel), `scene.js` (the 3D cell) | - |
| 7 | You press Reset, confirm the checklist, Start | `safety.js` buttons | `safety.py` `reset()`, `confirm_checklist()`, `start()` |
| 8 | The job plays | `app.js` `frame()`: moves time forward **only while** the safety controller says `may_move` | `safety.py` checks every input 10 times a second |
| 9 | The job ends | `app.js` `finishJob()` | `safety.py` `finished()`, `history.py` `add()` |

**Why the plan is made in Python, but played in the browser:** planning is heavy maths, done once.
Playing it back is just "where is each arm at time *t*" - the plan holds every arm's position
over time (its *tracks*), and `kinematics.js` `trackAt()` reads them. When the real machine is
built, the same plan goes to the motors instead of (as well as) the 3D view.

## 4. Safety: who is in charge

```mermaid
flowchart LR
    I1["E-stop, gate, light curtain<br/>(screen or real GPIO)"] --> SC
    I2["camera zones (vision.py)"] --> SC
    I3["sensors: object on bed, load, torch, fire"] --> SC
    I4["screen tick every 200 ms"] --> SC
    SC["safety.py<br/>SafetyController"] -->|"state, may_move,<br/>speed_factor, torch_allowed"| SCR["screen (safety.js / app.js)"]
    SCR -->|"motion only if may_move"| M["arms move"]
```

- **`safety.py` is the only place that decides** whether the machine may move. The screen never
  decides on its own; it asks and obeys (and stops by itself if it can't reach the controller).
- Every stop **latches**: clearing the cause is not enough - Reset, then Start.
- Each stop has a fixed **decision** for each hand (`DECISIONS` in `safety.py`, shown on the
  Sensors tab and in [SENSORS.md](SENSORS.md)).
- In the real machine the same functions must also be in certified safety hardware - see [SAFETY.md](SAFETY.md).

## 5. Every file, and what it is for

### The engine - `beamcell/`

| File | In one line |
|---|---|
| **`server.py`** | **master file**: web server; every `/api/...` request; starts everything |
| `config.py` | reads `config/cell.toml` (all the settings) |
| `safety.py` | the safety controller: states, stops, Reset/Start, modes, watchdog, decisions |
| `gpio_inputs.py` | real E-stop / gate / light-curtain / reset buttons on the Jetson's pins |
| `vision.py` | the camera: finds it, YOLO person detection, warning / danger zones |
| `sections.py` + `data/uk_sections.json` | every UK steel section (UB, UC, PFC, angles, hollow...) and its exact shape |
| `uk_codes.py` | the UK rule numbers: hole sizes, edge distances, grades |
| `parts.py` | a **Part** (holes, notches, mitres), its checks, and **nesting** onto bars |
| `nc1.py` | reads and writes DSTV NC1 files (Tekla, Advance Steel) |
| `manual.py` | manual cutting: turns your clicks (holes, cuts, notches) into a bar the planner understands |
| `machine.py` | the cell's sizes and the two hands (where they park, their reach) |
| `arm.py` | the 6-axis arm maths: joint angles for a tool position (inverse kinematics) |
| `planner.py` | **plans the job**: order of cuts, every move of both hands, timing |
| `plasma.py` | the plasma cut chart: amps, speed, heights, pierce time for each kind of cut |
| `plasma_presets.py` | saved plasma settings that worked (`plasma_settings/`), used by the planner instead of the chart |
| `reports.py` | a problem report for the developer every time the machine stops during a job (`reports/`) |
| `collisions.py` | checks the arms never touch the steel or each other |
| `sensors.py` | every sensor (simulated until fitted) and the bar check |
| `history.py` | the job history (`jobs/history.json`) |
| `assistant.py` | "what's happening" in plain words, and the optional AI advisor |
| `doctor.py` | system check: `python3 -m beamcell.doctor` |
| `cad.py` | makes the CAD (STEP files and the 3D view's models) - run on a PC, not needed on the Jetson |

### The screen - `web/`

| File | In one line |
|---|---|
| `index.html` | the page: every tab, button and box |
| `css/style.css` | how it looks |
| **`js/app.js`** | **master file**: starts everything; Machine tab; plans; plays the job (`frame()`); job finished |
| `js/api.js` | two helpers to talk to the engine: `get()` and `post()` |
| `js/scene.js` | the 3D cell (three.js): lights, the machine models, the arms, sparks, camera views |
| `js/kinematics.js` | where each arm is at time *t* (reads the plan's tracks) |
| `js/geometry.js` | turns a steel section and its cuts into 3D shapes |
| `js/parts.js` | Parts tab: list, editor, import, save / open jobs |
| `js/manual.js` | Manual cut mode |
| `js/safety.js` | Safety tab, the E-stop button, the 200 ms tick to the engine |
| `js/sensors.js` | Sensors tab: sensors, bar check, stops and decisions, plasma chart |
| `js/jobs.js` | the Job history & saved jobs window |
| `js/plasma.js` | Plasma tab: try, save and reuse settings; the Machine tab's plasma choice |
| `js/reports.js` | the Reports button and window: problem reports, send to the developer |
| `js/library.js` | Sections tab (and STL / STEP downloads) |
| `js/prototype.js` | Prototype tab: the 1:10 model with part numbers |
| `js/camera.js` | Camera tab |
| `js/help.js` | Help tab |
| `models/*.glb` | the machine's 3D models (made by `beamcell/cad.py`) |
| `vendor/` | three.js, the 3D library (kept here so no internet is needed) |

### Everything else

| Folder | What's in it |
|---|---|
| `config/cell.toml` | **all the settings** - safety, camera zones, GPIO pins, plasma chart, port |
| `docs/` | these documents, images, the video, the shopping list and assembly PDFs |
| `cad/` | STEP files: the whole cell, the 1:10 prototype, the example parts |
| `examples/nc1/` | example NC1 files |
| `tests/` | automatic tests - GitHub runs them on every push (`.github/workflows/tests.yml`) |
| `tools/` | makes the example files, the PDFs, the assembly pictures and the video |
| `deploy/` | start-at-boot service for the Jetson |
| `jobs/`, `logs/` | your saved jobs, job history and safety log (on the Jetson only, not on GitHub) |

## 6. Following one button click through the code

**"Plan this bar"** - a good one to trace yourself:

1. `web/index.html`: `<button id="btn-plan">Plan this bar</button>`
2. `web/js/app.js`, in `start()`: `$("btn-plan").onclick = planBar;`
3. `planBar()` sends the job: `post("/api/plan", { parts, stock_length, bar })` (`web/js/api.js`)
4. `beamcell/server.py`, `do_POST()`: `if path == "/api/plan": return self._send(200, plan_bar(body))`
5. `plan_bar()` re-nests the parts, takes the bar you chose, and calls `plan_output()`:
   `Plan(bar).build()` in `planner.py`, `collisions.check_plan()`, `sensors.measure_bar()`
6. The answer (JSON) comes back to `planBar()`, which calls `loadPlan(plan)` in `app.js`
7. `loadPlan()` fills in the plan box, builds the steel in 3D, and registers the job with the safety controller

Every other button works the same way: **HTML button → a function in a `web/js` file → `/api/...`
→ `server.py` → a module in `beamcell/` → JSON back → the screen updates.**

## 7. Where to change things

| You want to... | Change |
|---|---|
| change a setting (speeds, zones, checklist, plasma chart) | `config/cell.toml`, then restart |
| change a UK rule | `beamcell/uk_codes.py` / `parts.py` `check()` |
| change how fast plasma cuts, or use your own cut chart | `beamcell/plasma.py` `CHARTS`, or save tried settings on the Plasma tab |
| send problem reports somewhere else | `config/cell.toml` `[reports]` (`github_repo`, `webhook_url`) |
| change a safety rule or what a hand does on a stop | `beamcell/safety.py` (`FAULTS`, `DECISIONS`) - and update the risk assessment |
| add a sensor | `beamcell/sensors.py` `SENSORS` (it then appears on the Sensors tab) |
| change how something looks | `web/css/style.css`, `web/index.html` |
| change the machine's size or shape | `beamcell/machine.py`, then `python3 -m beamcell.cad` on a PC to rebuild the models |

After any change: `python3 -m unittest discover -s tests -t .` runs the tests (about a minute).

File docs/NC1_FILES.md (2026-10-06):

# NC1 (DSTV) files

NC1 is the plain-text format that steel detailing software writes for beam CNC machines:
one file per part. **Tekla Structures**, **Advance Steel** and **SDS2** all export it. The cell
reads it in `beamcell/nc1.py`.

## Getting NC1 files out of Tekla

In Tekla Structures: **Manufacturing → NC files → DSTV** (older versions: *File → Export →
NC files*). Pick the parts, choose the output folder, and Tekla writes one `.nc1` file per
part. Then drag the files onto the **Parts** tab. The exact menu names change between
Tekla versions - search the Tekla help for "NC files".

## What is read

| Block | What it is | What the cell does |
|---|---|---|
| `ST` | header: order, drawing, phase, **mark**, **grade**, **quantity**, **profile**, profile type, **length**, h, b, tf, tw, r, kg/m, paint area, **end-cut angles**, texts | used |
| `BO` | holes; with a slot length they're slotted holes | cut |
| `AK` | outer contour of a face: end cuts, mitres, notches/copes | cut |
| `IK` | inner contour: an opening inside a face | cut |
| `SI` | hard stamping (marks) | listed in the report, not cut |
| `KO`, `PU` | marking lines / powder marking | listed, not cut |
| `KA`, `SC`, `TO`, `UE` ... | bending, saw cuts, tolerances, camber | listed, not used |
| `EN` | end of the file | - |

Comment lines start with `**`.

### Header (ST) - one value per line, in this order
1 order, 2 drawing, 3 phase, 4 piece mark, 5 steel grade, 6 quantity, 7 profile name,
8 profile type (`I`, `U`, `L`, `M`, `RO`, `RU`, `B`, `C`, `T`), 9 length (and saw length after
a comma), 10 depth, 11 width, 12 flange thickness, 13 web thickness, 14 root radius,
15 kg/m, 16 paint m²/m, 17 web start cut, 18 web end cut, 19 flange start cut,
20 flange end cut, 21-24 texts.

### Profile names
Names like `UB457*191*67`, `UKB457x191x67`, `457x191x67UB`, `PFC200*90*30`, `L100*100*10`
are matched to the UK library. If a name isn't found (e.g. a European `HE300A`), the sizes in
the header are used and the report says so.

### Faces and coordinates (mm)
| Letter | Face | y is measured |
|---|---|---|
| `v` | front: the web, or the upright leg of an angle | up from the underside of the section |
| `o` | top flange | across from the front edge |
| `u` | bottom flange, or the flat leg of an angle | across from the front edge (the heel for angles) |
| `h` | behind: the back of the web | as `v` (holes go through the web) |

x is always along the part from its start.

**Please check this with your own files**: the DSTV standard defines exactly where y starts
on each face of each profile type, and some exporters have options. Import one of your parts,
look at the drawing on the Parts tab, and compare it with the Tekla drawing. If the holes
come out mirrored across a flange, tell the software maintainer which file and which face.

## Writing NC1

**Export NC1** on the Parts tab writes any part (including ones you made by hand) back out as
an NC1 file, with its holes and every face's outline, so it can go to a real beam line.

## Examples

`examples/nc1/` has seven files: notched secondary beams (B1), a trimmer (B2), a primary
beam with a service opening (G1), a column (C1), a channel (P1), bracing angles (A1) and one
laid out exactly like a Tekla export (T1).

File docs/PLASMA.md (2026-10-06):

# Plasma: how the torch finds the steel, holds its height, and changes for each cut

The Cutter's plasma settings come from a **cut chart** (`beamcell/plasma.py`). The planner uses
it for every cut, so the plan's timing is the real cutting speed. On the Machine tab, the Cutter's
card shows the settings of the cut it is doing: amps, speed, height, arc volts, and torch height control on or off.
The Sensors tab shows the whole chart.

> **The numbers are typical values for planning,** built from published cut charts for mild steel.
> Before cutting real steel, put in the cut chart of **your** plasma system and consumables, and
> qualify the process: BS EN ISO 9013 for cut quality, and BS EN 1090-2 for thermal-cut holes, which have hardness and quality requirements.

## 1. The nozzle-to-steel distance: how it is found and held

| Stage | What happens | Why |
|---|---|---|
| **Touch-off** (initial height sensing) | The torch moves down until the nozzle / shield touches the steel. A small voltage on the nozzle closes a circuit through the plate (**ohmic contact**). Or the Z axis feels the stall. | finds the **true surface**: beams are bowed, out of square and a few mm off their catalogue size |
| **Pierce height** | Lift to about 2x the cut height, fire the arc, wait the **pierce delay** | molten metal splashes up while piercing; height keeps it off the nozzle |
| **Edge start** | Cuts that start at a flange edge need **no pierce**: the arc starts on the edge | faster, and the nozzle lasts longer |
| **Cut height** | Drop to the cut height and move at the cut speed | the height sets the bevel and quality of the cut |
| **Torch height control (THC)** | The arc voltage rises when the torch is higher and falls when lower; the controller moves Z to hold the **target arc voltage** | holds the height over a bowed or uneven beam |
| **THC off** | On holes, in tight corners and near edges | there, the voltage jumps for other reasons, and the torch would dive into the steel |
| **Collision** | A magnetic **breakaway** mount lets the torch snap off if it hits something; its switch stops the machine | protects the torch and the arm |

On the 1:10 prototype the "torch" is a pen in a sprung holder. Z moves down until a **micro-switch
on the holder** closes. That is the same idea as touch-off, with no arc and no arc voltage.

## 2. The parameters and what changes them

| Parameter | Set by | Typical (O2 plasma, 10 mm) |
|---|---|---|
| **Current (amps)** | plate thickness: up to 12 mm at 130 A, up to 25 mm at 170 A, thicker at 300 A | 130 A |
| **Gas** | process: O2 plasma with an air shield for mild steel (best edges); air plasma on small machines | O2 / air |
| **Cut speed** | thickness and amps, then reduced for the kind of cut | 2,700 mm/min |
| **Arc voltage** (= height during the cut) | thickness and amps | 135 V |
| **Cut height** | consumables | 3.0 mm |
| **Pierce height** | about 2x cut height | 6.6 mm |
| **Pierce delay** | thickness (longer for thicker plate) | 0.5 s |
| **Kerf** (width of the cut) | amps and consumables; the path is offset by half of it | 2.5 mm |

On a UB 305x165x40 the web (6.0 mm) and the flanges (10.2 mm) get different settings, and the
planner uses the right one for each pass.

## 3. Cutting scenarios

| Scenario | Speed | Start | Torch height control | Notes |
|---|---|---|---|---|
| **Straight cut through the section** (cut-to-length, mitre) | 100 % | edge start | on, off near the edges | a mitre in plan is still a vertical cut: same thickness, longer path |
| **Notch (cope)** with a radius | 100 %, **50 % in the corners** | edge start | on along the straights, off in the corners and radius | minimum cope radius from the UK checks (Blue Book) |
| **Bolt hole** | **60 %** | pierce in the centre, **lead-in arc** | **off** | bolt-ready holes need diameter at least equal to the plate thickness (**d/t ≥ 1**); d/t from 1 to 1.5 needs the full hole recipe (Hypertherm "True Hole" type: gas, speed changes around the hole, arc off on time); **d/t < 1: drill it** |
| **Slotted hole** | 65 % | pierce in the centre | off | as holes |
| **Opening / cut-out** | 80 %, 50 % in corners | pierce inside the waste, lead-in | on along the straights | |
| **Very thick plate** (above the pierce limit, 50 mm at 300 A) | - | **edge start only** or drill a start hole | - | the planner warns |
| **Bevel** (weld prep, torch tilted) | slower: the steel is effectively thicker (t / cos angle) | - | - | not in the planner yet |

The planner reports these as warnings on the plan, for example a hole that must be drilled, or
plate too thick to pierce.

## 4. Choosing the chart

`config/cell.toml`:

```toml
[plasma]
process = "o2"     # "o2" production O2 plasma, "air" air plasma, "pen" the 1:10 prototype's pen
```

To use your own machine's numbers, edit the rows in `beamcell/plasma.py` (`CHARTS`). Each row is
thickness, speed, arc volts, cut height, pierce height, pierce delay and kerf. Then restart the app.

## 5. Saved settings: the numbers that worked on YOUR machine

A cut chart is only a starting point. Plasma behaves differently with every machine, set of
consumables, gas supply and batch of steel, so the right numbers have to be found by trying them.
The **Plasma** tab is for that:

1. **Start new settings**: pick the beam (for example UB 305x165x40), the grade and the plasma.
   The numbers are filled in from the cut chart. A beam has two thicknesses, so there is a column
   for the **web** and one for the **flange**.
2. Cut a test piece. Change the numbers until the cut is clean: square edges, little dross, holes
   the right size. Changed numbers are highlighted, with the chart's value in grey beside them.
3. Mark it **Works well** (or *Still trying* / *Doesn't work*), write what you saw in **Notes**,
   and **Save**. Each one is a file named after the beam, in `plasma_settings/` (for example
   `plasma_settings/UB 305x165x40 S355.json`).
4. Next time you cut that beam, the Machine tab picks its saved settings automatically (the ones
   marked *Works well* first). The **Plasma** list above **Plan** shows which are used, and you can
   choose others or the plain cut chart. A saved job remembers its plasma settings too.

What each saved setting holds, for the web and for the flange: thickness, current (A), cut speed,
hole speed, corner speed (% of the cut speed), arc voltage, cut height, pierce height, pierce delay,
kerf width, gas pressure and torch height control on/off. Holes always cut with height control off,
and edge starts skip the pierce delay.

`plasma_settings/` stays on the machine (it is not in git, so `git pull` never touches it).
**Back it up**: it holds what you learned.

Sources: Hypertherm, *Torch height control for plasma cutting* and *True Hole technology*; Hypertherm
XPR300 published cut speeds for mild steel; BS EN ISO 9013; BS EN 1090-2.

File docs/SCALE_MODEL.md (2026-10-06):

# Building a scale model of the cell

You can build the cell yourself at any scale. All the sizes below come from the software
(`beamcell/machine.py`), so the model matches what you see on screen.

## 1. Get the 3D files

Open the app, go to the **Sections** tab:

- **Download section STL**: any UK section (UB, UC, PFC, angles, hollow sections) at any
  length and scale. The STL is in millimetres, already scaled, ready for a slicer.
- **Download whole machine STL**: the whole cell (runways, columns, bridges, both arms in
  their current pose, bed, outfeed table, fence posts) at the chosen scale. Pause the machine where
  you like the pose first.

The panel tells you the printed size and warns when a wall becomes too thin to print
(under about 0.8 mm with a 0.4 mm nozzle).

## 2. Choosing a scale

| Scale | 12 m work area | Cell (with parking) | Rail height | UB 457 beam | Good for |
|---|---|---|---|---|---|
| 1:10 | 1200 mm | 1460 x 300 mm | 340 mm | 45 x 19 mm | the working prototype ([PROTOTYPE.md](PROTOTYPE.md)) - 1:10 with a 600 mm bed |
| 1:20 | 600 mm | 730 x 150 mm | 170 mm | 23 x 9.5 mm | a desk model, fully 3D printed |
| 1:25 | 480 mm | 585 x 120 mm | 136 mm | 18 x 7.6 mm | a desk model |
| 1:50 | 240 mm | 290 x 60 mm | 68 mm | 9 x 3.8 mm | display only (thin parts are fragile) |
| 1:100 | 120 mm | 146 x 30 mm | 34 mm | 4.5 x 1.9 mm | display only, resin printer |

At 1:50 and 1:100 the flanges and webs are thinner than a normal 3D printer can make
(a 10 mm web becomes 0.2 mm at 1:50). Print them with a resin printer, or thicken them
(print the section at 1:20 and use it as a "chunky" stand-in).

## 3. The machine's sizes (full size, metres)

| Item | Size |
|---|---|
| Work area (stock bar) | 12.0 m long, X from 0 to 12 |
| Rails | X from -1.3 to 13.3 (room to park both bridges), 3.0 m apart, top at 3.4 m |
| Runway beams | UB 457x191 on their side, on UC 254x254 columns (5 per side) |
| Bed (rollers) | top at 0.9 m, along Y = -0.5 m (the bar's centre line) |
| Outfeed table | top at 0.9 m, along Y = +0.85 m |
| Bed rollers | 100 mm diameter, every 1 m from x = 0.5 m, top at 0.9 m |
| Bridges | box girder 0.32 x 3.5 m, 0.42 m deep, one for each hand |
| Column (Z axis) | arm base from 1.25 m to 3.0 m above the floor |
| Bridges never closer than | 1.0 m centre to centre |

**Cutter arm** (UR5-like, hangs upside down): upper arm 425 mm, forearm 392 mm, wrist
offsets 109 / 95 / 82 mm, torch 400 mm long.

**Handler arm** (1.3x bigger): upper arm 552 mm, forearm 510 mm, wrist offsets 142 / 123 /
107 mm, magnet 120 mm, payload 500 kg.

## 4. A working prototype

For a model that really moves, see **[PROTOTYPE.md](PROTOTYPE.md)**: a 1:10 desk-top version
with its CAD (`cad/prototype_1to10.step`), assembly drawing, cut list, shopping list (~£1,150),
safety wiring and build stages.

This page is for static display models.

## 5. Tips

- Print sections lying on a flange (I sections) or flat leg (angles) so no supports are needed.
- Paint the runways grey, the bridges safety yellow (RAL 1003), the Cutter orange and the
  Handler blue so it matches the screen.
- Mark the work area 0 to 12 m on the base every metre - it makes the demo easy to follow.

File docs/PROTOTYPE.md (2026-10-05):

# The 1:10 working prototype - what to buy and how to build it

A **desk-top version of the cell at 1:10** that really moves: two gantry bridges, two small
servo arms, cameras with YOLO, and a real hard-wired E-stop. It proves the software, the motion
planning, the vision and the safety circuit before anything full size is built.

- **Size:** about 1.1 m x 0.4 m x 0.45 m with the control box - it fits on a desk.
- **Shopping list:** `docs/Prototype_Shopping_List.pdf` (print it, tick as you buy) or
  `docs/prototype_bom.csv` (Excel / Google Sheets). Every line has a **part number** P01 ...
- **Assembly drawing:** `docs/Prototype_Assembly.pdf` - views with part-number balloons, an exploded
  view, every position, the parts list and the position list. In the app: the **Prototype** tab
  (3D, click any part, explode slider). Positions P11-1, P11-2 ... are the copies of a part (also in
  `cad/prototype_positions.csv` and the CAD tree).
- **CAD:** `cad/prototype_1to10.step` (Fusion 360 / SolidWorks / FreeCAD / Onshape).
- **Cut list:** `cad/prototype_cut_list.csv` - every aluminium length, from the CAD.

Rebuild after changing the design: `python3 -m beamcell.cad prototype` (on a PC), then
`python3 tools/make_bom_pdf.py` and `python3 tools/make_assembly_pdf.py`.

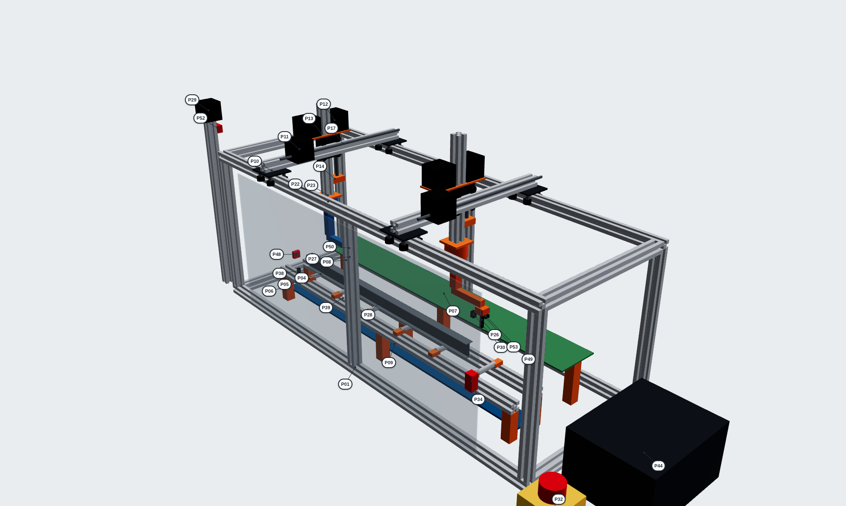
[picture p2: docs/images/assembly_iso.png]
The 1:10 prototype with part numbers


## What it is (honestly)

| | Full size | 1:10 prototype |
|---|---|---|
| Bed | 12 m (6 m bars) | 600 mm (a 6 m bar at 1:10) - set `PROTO_LENGTH = 1200` in `beamcell/cad.py` for the full 12 m |
| Width between rails / rail height | 3 m / 3.4 m | 300 mm / 340 mm |
| Frame | steel runways on columns | 20x20 aluminium V-slot only |
| Bridges | steel box girders, servo drives | 20x20 on mini V-wheels, NEMA 17 + GT2 belts |
| Lift (Z) | 2 m mast | 200 mm 20x20 on a T8 lead screw |
| Arms | 6-axis industrial arms | MeArm-type arms: 4 MG90S micro servos each, about 150 mm reach |
| Cutter | 130 A plasma torch | **a fine-liner pen** in a sprung holder: it marks every cut line |
| Handler | 500 kg lifting magnet | 5 V 20 mm electromagnet |
| Steel | UK sections | 3D-printed UK sections at 1:10 (UB 305 = 30 x 16 mm) with steel tape on top |

**No real cutting on the prototype.** A plasma torch, a laser over Class 2 or a spindle would make a
desk model dangerous (UV, fumes, fire, eyes). The pen proves what the software has to prove: where
each hole, notch and cut-off is, in what order, and that the paths are right.

**Know before you build:**
1. The small arms have **4 servos** (base, shoulder, elbow, wrist), not 6 like the simulated arms.
   They point the pen straight down well; marking the web from the side needs the wrist tilted,
   which they can do in a narrower range. The arm maths for them has to be added (stage 5b).
2. The arms are driven by a **PCA9685 servo board** wired straight to the Jetson's 40-pin header
   (I2C, pins 3 and 5) - no extra controller. The stepper motors need the **FluidNC board**: Linux
   can't make exact step pulses; the Jetson sends it G-code over USB. It's flashed once from a web
   page - no Arduino programming.
3. At 1:10 the model beams are small and light: print them in PETG and put steel tape on the top
   flange so the magnet can lift them.

## Total cost

About **£1,150** for everything, about **£1,260** with 10% spare for postage and
price changes (October 2026 prices; check before you buy). The safety relay is the biggest single
item (~£180 new, ~£75 used) - **don't skip it or the E-stop**; wiring them properly is part of the point.
To get the gantry moving first (stages 1-2): about £430.

## Wiring the safety circuit - build it FIRST, before motors move

```
 mains -> IEC inlet (switch + fuse) -> 24 V supply (motors, controller) and 5 V supply (servos, magnet)
                                          |                      |
                       PNOZ s3 output contacts, opened by:
                         - E-stop (NC contact 1 -> channel 1, NC contact 2 -> channel 2)
                         - door interlock switch (in series with the E-stop)
                         - reset: blue button (manual, monitored)
                                          |                      |
                              24 V to the motor drivers     5 V to the servos + magnet
 The Jetson and the FluidNC logic stay powered: they REPORT the stop, they don't make it.
 A spare NC contact on the E-stop -> Jetson GPIO (docs/SAFETY.md section 6) -> the app shows E-STOP.
```

## Build stages

| Stage | What you build | Done when |
|---|---|---|
| 0 | Software on the Jetson (`./start.sh`), `python3 -m beamcell.doctor --save` | the app runs, the doctor is green |
| 1 | Frame, bed, outfeed table, scrap tray (cut list + printed parts) | square and level |
| 5 | **Safety circuit and enclosure next** - E-stop, safety relay, door switch, reset | E-stop and door cut motor and servo power (measure it) |
| 2 | Bridges, carriages, Z axes, motors, FluidNC, limit switches | every axis homes and jogs from the FluidNC web page |
| 4 | Cameras on the Jetson, YOLO zones on the Camera tab | a hand in the danger zone stops the app |
| 3 | Build the two arms, PCA9685 on the Jetson, mount the arms under the Z axes | each servo moves from a test script |
| 5b | Software: send the planned moves to FluidNC (G-code) and the arms (PCA9685) | the prototype marks a B1 beam like the 3D view |
| 6 | Magnet on the Handler: lift a marked part to the outfeed table | part lands flat on the table |

## The shopping list

Same as `docs/prototype_bom.csv` and the PDF. Prices approximate (GBP, incl. VAT where known).

### Stage 1 - frame and bed (about £130)

| Part | Item | What to look for | Qty | ~£ each | Where |
|---|---|---|---|---|---|
| P01 | V-slot 20x20 aluminium extrusion | cut to size - lengths in cad/prototype_cut_list.csv (frame, bed rails, bridges, Z axes, camera post) *(the whole frame is 20x20; lengths come from the CAD model)* | 9.5 m | 8 | [Ooznest (cut to size), Amazon UK](https://ooznest.co.uk/?s=20x20mm+V-Slot+cut+to+size&post_type=product) |
| P02 | Corner brackets + M5 T-nuts + M5 bolts | 30 cast 20-series corner brackets, 120 drop-in T-nuts, M5x8 button heads | 1 kit | 30 | [Ooznest, Amazon UK](https://ooznest.co.uk/?s=cast+corner+bracket+20+series&post_type=product) |
| P03 | Rubber feet | stick-on rubber feet 20 mm *(stops it sliding on the desk)* | 4 | 1 | [Amazon UK](https://www.amazon.co.uk/s?k=rubber+feet+20mm+self+adhesive) |
| P04 | Bed rollers | 10 mm printed sleeves on 3 mm silver steel rod (50 mm), 2 x 623ZZ bearings each *(print the sleeves; buy rod and bearings)* | 6 | 2 | [Amazon UK, Simply Bearings](https://www.amazon.co.uk/s?k=623ZZ+bearings+3mm) |
| P05 | Roller brackets (3D printed) | PETG, clip on the 20x20 bed rails *(filament counted under Consumables)* | 12 | 0 | print |
| P06 | Bed riser blocks (3D printed) | PETG blocks that hold the bed rails 60 mm above the base *(filament counted under Consumables)* | 6 | 0 | print |
| P07 | Outfeed table board | 3 mm plywood strip 700 x 90 mm | 1 | 4 | [builders' merchant, Amazon UK](https://www.amazon.co.uk/s?k=3mm+plywood+sheet) |
| P08 | Outfeed table risers (3D printed) | PETG *(filament counted under Consumables)* | 3 | 0 | print |
| P09 | Scrap tray (3D printed) | 700 x 44 mm tray under the bed *(filament counted under Consumables)* | 1 | 0 | print |

### Stage 2 - motion and controller (about £300)

| Part | Item | What to look for | Qty | ~£ each | Where |
|---|---|---|---|---|---|
| P10 | Mini V-wheel gantry plate kits | 20-series mini gantry plate + 4 mini V-wheels (625 bearings) + eccentric spacers *(2 per bridge end x 2 bridges + 1 per carriage x 2)* | 6 | 12 | [Ooznest](https://ooznest.co.uk/?s=mini+V-wheel+gantry+plate&post_type=product) |
| P11 | NEMA 17 stepper motor | 1.5-2 A, 40 mm body, 5 mm shaft (a NEMA 14 is lighter if you prefer) *(X (one per bridge) and Y (one per carriage))* | 4 | 12 | [Ooznest, StepperOnline](https://www.omc-stepperonline.com/search?search=nema+17+stepper+motor+40mm) |
| P12 | NEMA 17 with integrated T8 lead screw | T8 x 2 mm lead, 150 mm screw, with brass nut *(Z axes)* | 2 | 22 | [StepperOnline, Amazon UK](https://www.omc-stepperonline.com/search?search=nema+17+lead+screw+T8+150mm) |
| P13 | Z motor bracket (3D printed) | PETG shelf on top of the carriage plate, holds the Z and Y motors *(filament counted under Consumables)* | 2 | 0 | print |
| P14 | Lead-screw nut block (3D printed) | PETG block with the brass T8 nut, fixed to the Z axis *(filament counted under Consumables)* | 2 | 0 | print |
| P15 | GT2 belt 6 mm | 5 m (2 per bridge along the rails, 1 per carriage) | 1 | 8 | [Ooznest](https://ooznest.co.uk/?s=GT2+belt+6mm&post_type=product) |
| P16 | GT2 16T pulleys + idlers | 4 x 16T 5 mm bore (cross shafts), 2 x 16T (Y), 8 idlers | 1 set | 20 | [Ooznest, Amazon UK](https://ooznest.co.uk/?s=GT2+pulley+16+tooth&post_type=product) |
| P17 | 5 mm cross shafts + bearings | 2 x 360 mm 5 mm silver steel, 4 x 625ZZ in printed blocks, 2 x 5-5 mm couplers *(one motor drives both rails of a bridge)* | 1 set | 12 | [Amazon UK, Simply Bearings](https://www.amazon.co.uk/s?k=5mm+linear+shaft+400mm) |
| P18 | Home / limit switches | mechanical microswitch with lever, NC wiring *(one per axis + 2 spare)* | 8 | 1.50 | [Amazon UK](https://www.amazon.co.uk/s?k=micro+limit+switch+lever+pack) |
| P19 | FluidNC 6-axis CNC controller (ESP32) | 6 driver sockets, USB to the Jetson (e.g. Elecrow / Bart Dring 6x CNC Controller) *(flash once from the web installer - no programming)* | 1 | 40 | [Elecrow, Tindie](https://www.elecrow.com/6x-cnc-controller-for-fluidnc.html) |
| P20 | TMC2209 stepper driver modules | StepStick format *(quiet; one per axis)* | 6 | 5 | [Amazon UK, Ooznest](https://www.amazon.co.uk/s?k=TMC2209+stepper+driver+stepstick) |
| P21 | Motor cable + drag chain | 5 m 4-core 0.25 mm2, 1 m 7x7 drag chain | 1 set | 15 | [Amazon UK](https://www.amazon.co.uk/s?k=4+core+cable+0.25mm+drag+chain+7x7) |

### Stage 3 - arms and tools (about £100)

| Part | Item | What to look for | Qty | ~£ each | Where |
|---|---|---|---|---|---|
| P22 | MeArm-type 4-servo arm kit | small 4-servo arm with MG90S metal-gear micro servos (reach ~150 mm); swap the gripper for the pen / magnet *(about £37 each (MeArm pocket-sized kit))* | 2 | 37 | [Cool Components, Kitronik](https://coolcomponents.co.uk/collections/kits/robotic-arm) |
| P23 | Arm mount plate (3D printed) | PETG plate: bolts the arm base under the Z axis *(filament counted under Consumables)* | 2 | 0 | print |
| P24 | PCA9685 16-channel servo board | I2C - wired straight to the Jetson's 40-pin header (pins 3 / 5), drives all 8 servos *(no extra controller needed for the arms)* | 1 | 6 | [Amazon UK, kunkune](https://kunkune.co.uk/?p=11021) |
| P25 | 5 V power supply for the servos | Mean Well LRS-35-5 (5 V 7 A) - servos and magnet | 1 | 12 | [RS, Farnell](https://uk.rs-online.com/web/c/?searchTerm=Mean+Well+LRS-35-5) |
| P26 | Cutter 'torch' for the prototype (pen holder) | fine-liner pen in a sprung 3D-printed holder (marks every cut line on the model beam) *(no real cutting on the prototype: see docs/PROTOTYPE.md)* | 1 | 2 | print |
| P27 | Handler magnet | 5 V 20 mm lifting electromagnet (~2.5 kg hold) + MOSFET module + flyback diode *(switch it from a FluidNC output)* | 1 | 8 | [Amazon UK](https://www.amazon.co.uk/s?k=5V+electromagnet+20mm+lifting) |
| P28 | Model beams (3D printed) | UB 305x165 at 1:10 (30 x 16 mm), 500 mm long, with steel tape on the top flange *(the magnet needs steel to grip; filament counted under Consumables)* | 4 | 0 | print |

### Stage 4 - cameras and sensors (about £130)

| Part | Item | What to look for | Qty | ~£ each | Where |
|---|---|---|---|---|---|
| P29 | USB wide-angle camera (safety zone) | 1080p UVC, 90-120 deg view (e.g. Logitech C920/C922 or an Arducam USB wide-angle) *(plug and play on the Jetson; YOLO watches the cell)* | 1 | 50 | [Amazon UK, Pimoroni](https://www.amazon.co.uk/s?k=Logitech+C920+webcam) |
| P30 | CSI camera (close-up of the Cutter) | Arducam IMX219 for Jetson Orin Nano (22-pin cable), wide-angle lens *(optional; checks the marked lines)* | 1 | 25 | [Arducam, RobotShop UK](https://www.arducam.com/arducam-imx219-pdaf-cdaf-autofocus-camera-module-with-case-for-raspberry-pi-nvidiar-jetson-orin-series.html) |
| P31 | Powered USB 3 hub | 4-port, own power supply *(controller + camera (+ spare))* | 1 | 20 | [Amazon UK](https://www.amazon.co.uk/s?k=powered+USB+3.0+hub+4+port) |
| P48 | VL53L1X time-of-flight distance sensor | I2C breakout, up to 4 m - the datum sensor: finds where the model beam starts *(on the Jetson's I2C with the PCA9685)* | 1 | 12 | [Pimoroni, The Pi Hut](https://shop.pimoroni.com/search?q=VL53L1X) |
| P49 | Pen touch-off micro-switch | micro-switch with roller lever, on the sprung pen holder - finds the beam surface (the prototype's initial height sensing) *(one spare)* | 2 | 1.5 | [Amazon UK, CPC](https://www.amazon.co.uk/s?k=micro+switch+roller+lever) |
| P50 | Load cell 1 kg + HX711 | bar load cell 1 kg with HX711 amplifier - between the Handler's wrist and magnet: weighs the part (slipping, wrong part, not cut free) | 1 | 7 | [Amazon UK, The Pi Hut](https://www.amazon.co.uk/s?k=load+cell+1kg+HX711) |
| P51 | INA219 current sensor | I2C current sensor in the magnet supply - checks the magnet is really on *(not drawn (wiring, inside the box))* | 1 | 5 | [Pimoroni, Amazon UK](https://www.amazon.co.uk/s?k=INA219+current+sensor) |
| P52 | IR flame sensor module | IR flame sensor with digital output - demonstrates the fire detector *(NOT a certified fire detector - demo only)* | 1 | 3 | [Amazon UK](https://www.amazon.co.uk/s?k=IR+flame+sensor+module) |
| P53 | Line laser module (Class 2) | 650 nm line laser, Class 1 or 2 (1 mW or less) - with camera 2 it shows the beam's real profile *(never look into the beam; Class 2 or below only)* | 1 | 6 | [Amazon UK](https://www.amazon.co.uk/s?k=line+laser+module+650nm+1mW) |

### Stage 5 - safety and enclosure (about £360)

| Part | Item | What to look for | Qty | ~£ each | Where |
|---|---|---|---|---|---|
| P32 | Emergency stop station | yellow box, red 40 mm mushroom, turn to release, 2 NC contacts (e.g. Schneider Harmony XALK178 family) *(BS EN ISO 13850; NC contacts to the safety relay - add an NO/NC block for the Jetson)* | 1 | 42 | [RS, Farnell, TME](https://uk.rs-online.com/web/c/?searchTerm=XALK178) |
| P33 | Safety relay | Pilz PNOZ s3 24 V DC (dual channel, manual reset) or equivalent *(cuts the 24 V motor and 5 V servo supplies - this is how a real machine does it)* | 1 | 180 | [RS, Farnell (new) / ~£75 used](https://uk.farnell.com/search?st=PNOZ+s3+751103) |
| P34 | Door interlock switch | non-contact coded magnetic safety switch, NC (e.g. Pilz PSEN or Schmersal BNS) *(BS EN ISO 14119; wired into the safety relay)* | 1 | 60 | [RS, Farnell](https://uk.rs-online.com/web/c/?searchTerm=non+contact+safety+switch+coded) |
| P35 | Reset push button | 22 mm blue illuminated, 1 NO *(outside the enclosure with a view inside)* | 1 | 8 | [RS, Amazon UK](https://uk.rs-online.com/web/c/?searchTerm=22mm+blue+illuminated+push+button) |
| P36 | Stack light | 24 V mini LED tower, red / amber / green *(driven by the Jetson through a relay module)* | 1 | 15 | [Amazon UK](https://www.amazon.co.uk/s?k=24V+mini+LED+stack+light+3+colour) |
| P37 | 4-channel relay module (opto-isolated) | 3.3 V logic input, 24 V contacts *(stack light and magnet)* | 1 | 8 | [Amazon UK](https://www.amazon.co.uk/s?k=4+channel+relay+module+optocoupler+3.3V) |
| P38 | IR break-beam sensor pair | 5 mm IR break-beam (demonstrates the light-curtain input) *(one pair demonstrates the light curtain, one is the bar-present photo-eye - NOT a safety light curtain)* | 2 | 6 | [Pimoroni, The Pi Hut](https://thepihut.com/search?q=IR+break+beam+sensor) |
| P39 | Polycarbonate sheet 2 mm | front door, ends and lid (~0.6 m2) - polycarbonate, not acrylic (acrylic shatters) | 0.6 m2 | 35 | [plastics stockist, Amazon UK](https://www.amazon.co.uk/s?k=2mm+polycarbonate+sheet+clear) |
| P40 | Hinges + handle | 2 small hinges, 1 handle (20-series) | 1 set | 12 | [Ooznest, Amazon UK](https://ooznest.co.uk/?s=hinge+20+series&post_type=product) |

### Stage 6 - electrical (about £90)

| Part | Item | What to look for | Qty | ~£ each | Where |
|---|---|---|---|---|---|
| P41 | 24 V power supply | Mean Well LRS-100-24 (24 V 4.5 A) - motors, controller, safety circuit | 1 | 14 | [RS, Farnell](https://uk.rs-online.com/web/c/?searchTerm=Mean+Well+LRS-100-24) |
| P42 | IEC mains inlet with switch and fuse | panel mount, 3 A fuse *(have the mains side checked by a competent person)* | 1 | 8 | [RS, Farnell](https://uk.rs-online.com/web/c/?searchTerm=IEC+inlet+switch+fuse) |
| P43 | DIN rail + terminals + fuse holders | short 35 mm DIN rail, 12 terminals, 3 x 5x20 fuse holders | 1 set | 20 | [RS, Farnell](https://uk.rs-online.com/web/c/?searchTerm=DIN+rail+terminal+block+fuse+holder) |
| P44 | Control box | ABS enclosure ~200 x 160 x 110 with cable glands *(holds the Jetson too)* | 1 | 20 | [RS, CPC](https://uk.rs-online.com/web/c/?searchTerm=ABS+enclosure+200x160) |
| P45 | Wire + ferrules + crimp tool | 0.5 and 0.75 mm2 flexible, ferrule kit | 1 set | 25 | [Amazon UK, CPC](https://www.amazon.co.uk/s?k=ferrule+crimp+tool+kit) |
| P46 | Jetson Orin Nano Super (4 GB) | you already have it - docs/JETSON_SPECS.md *(runs the app, YOLO, the planner and the arms)* | 1 | 0 | - |

### Consumables (about £40)

| Part | Item | What to look for | Qty | ~£ each | Where |
|---|---|---|---|---|---|
| P47 | PETG and PLA filament | 1 kg each *(brackets, risers, tray, model beams, arm parts)* | 2 | 20 | [Amazon UK, 3DJake](https://www.amazon.co.uk/s?k=PETG+filament+1kg+1.75mm) |

**Total: about £1,150.**

## Safety rules for the prototype (it's still a machine)

- Do the risk assessment in `docs/SAFETY.md` for the prototype too - belts, lead screws and servo
  arms can pinch fingers, and the mains side can kill.
- Have the mains wiring (IEC inlet to the power supplies) checked by a competent person.
- Keep the polycarbonate door closed while it runs (the door switch stops it if you don't).
- No lasers above Class 2, no plasma, no spindle on the prototype.
- If other people will use it at work, PUWER 1998 applies: training, the E-stop, guards.

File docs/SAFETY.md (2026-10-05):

# Safety - stops, rules and regulations (UK)

**Read this first.** The cell's software has the stops a real machine needs, and they behave
the way the standards require (latching, reset, separate start, watchdogs, reduced speed,
hold-to-run). That makes the prototype safe to *demonstrate* and teaches the right
procedures. But a Jetson, Python and a web browser are **not safety-rated**. On any machine
that can hurt someone, every safety function below must be done in **hard-wired safety
hardware** (a safety relay or safety PLC, certified components), designed and validated by a
competent person. The software then only *reports* the safety state; it never *is* the
safety system. A camera with AI (YOLO) is never a safety device.

## 1. UK law that applies

| Law | What it means for this cell |
|---|---|
| Health and Safety at Work etc. Act 1974 | the general duty to keep people safe |
| Management of Health and Safety at Work Regulations 1999 (reg 3) | a written **risk assessment** |
| **PUWER 1998** (Provision and Use of Work Equipment) | reg 11 guard dangerous parts; reg 14 start controls; reg 15 stop controls; **reg 16 emergency stops**; reg 17-18 controls and control systems; reg 19 isolation; reg 24 warnings; reg 9 training |
| Supply of Machinery (Safety) Regulations 2008 | if the machine is supplied/put into service: essential requirements, technical file, conformity assessment, Declaration of Conformity, **UKCA** marking |
| **LOLER 1998** | the Handler's magnet lifts loads: lifting equipment - thorough examination (at least every 6 months for lifting accessories), safe working load marked |
| **COSHH 2002** + HSE guidance | plasma cutting fume from steel is a **carcinogen**: local exhaust ventilation (LEV), LEV thoroughly examined at least every 14 months, RPE where needed |
| Control of Noise at Work Regulations 2005 | plasma is loud: assess, hearing protection zone if over 85 dB(A) |
| Control of Artificial Optical Radiation at Work Regulations 2010 | the plasma arc's UV: screens, eye protection |
| Electricity at Work Regulations 1989 (and BS 7671 wiring) | electrical safety of the installation |
| Personal Protective Equipment at Work Regulations 1992 (amended 2022) | PPE as the last line |
| Regulatory Reform (Fire Safety) Order 2005 | sparks and hot work: fire risk assessment, extinguisher |
| Workplace (Health, Safety and Welfare) Regulations 1992 | marked walkways, lighting |
| RIDDOR 2013 | reporting serious incidents |

## 2. Standards used for the design

| Standard | Used for |
|---|---|
| BS EN ISO 12100 | risk assessment method (find hazards, estimate, reduce) |
| BS EN ISO 13849-1 / -2 | safety-related control systems: Performance Level (PL) and validation |
| BS EN 60204-1 | electrical equipment of machines: **stop categories 0/1/2**, E-stop, reset |
| BS EN ISO 13850 | emergency stop design (red mushroom on yellow, latching, twist to release) |
| BS EN ISO 10218-1 / -2 | industrial robots and robot cells: modes, **reduced speed 250 mm/s**, enabling device |
| BS EN ISO 14119 | interlocks on guards (the gate) |
| BS EN ISO 14120 | fixed and movable guards (the fence) |
| BS EN ISO 13857 | safety distances so people can't reach in |
| BS EN ISO 13855 | **where to mount a light curtain** (S = K x T + C) |
| BS EN IEC 61496-1/-2 | light curtains (Type 4) |
| BS EN ISO 17916 | **safety of thermal cutting machines** (the plasma cell) |
| BS EN 60974-1 | plasma cutting power sources |
| BS EN 13155 | non-fixed load lifting attachments (the magnet) |

## 3. Safety functions - in the software now, and what the real machine needs

| # | Function | In this prototype (software) | Real machine (hardware) - target |
|---|---|---|---|
| SF1 | **Emergency stop** | red E-STOP button on every screen + **Esc** key + optional wired button; latches; category 0 (or 1); release does not restart; Reset then Start | E-stops at the desk, the gate and each end; safety relay/PLC cuts drive power; **PL d, Cat 3** |
| SF2 | **Gate interlock** | gate open in Auto = protective stop (cat 1), latched until closed + Reset | coded interlock switch with guard locking until motion has stopped; **PL d** |
| SF3 | **Light curtain** (infeed) | beam broken in Auto = protective stop, latched | Type 4 curtain mounted at the BS EN ISO 13855 distance (shown on the Safety tab); **PL d/e** |
| SF4 | **Manual mode** | speed limited to 250 mm/s, **hold-to-run** (moves only while held) | safe-limited speed in the drives + 3-position enabling device; **PL d** |
| SF5 | **Maintenance / isolation** | Maintenance mode = isolated, nothing moves; needs Lock Out Tag Out confirmed; checklist again afterwards | lockable main isolator, personal padlocks (LOTO procedure), stored energy released |
| SF6 | **Fume extraction interlock** | no start without extraction; extraction stops = protective stop | airflow switch on the LEV wired to the plasma enable |
| SF7 | **Reset** | only works when every cause is gone; never starts the machine | blue reset button outside the cell with a view of the cell, monitored (falling edge) |
| SF8 | **Watchdogs** | operator screen silent > 2 s, or a required camera silent > 1.5 s = stop | safety PLC monitors its own I/O and communications |
| SF9 | **Bridge separation** | planner keeps bridges >= 1 m apart at all times; collision check | safe position monitoring / mechanical buffers on the rails |
| SF10 | **Camera zones (YOLO)** | warning zone slows to 25%; danger zone = protective stop | **extra layer only** - not safety-rated, never replaces SF1-SF4 |
| SF11 | **Magnet load loss** | Handler lifts max 500 kg; heavier parts left for the crane | battery-backed or permanent electro-magnet (no drop on power loss), BS EN 13155, LOLER |

**Stop categories (BS EN 60204-1):** 0 = power removed at once; 1 = controlled stop, then power
removed; 2 = controlled stop, power kept (normal Pause). The Safety tab shows which one
happened.

**Hazards beyond people** - an object on the bed, a slipping load, a torch collision, a fire - and the
fixed decision each hand makes for every stop are in [SENSORS.md](SENSORS.md#3-hazards-what-is-detected-and-what-each-hand-decides).

## 4. Operating procedure (what the screens enforce)

1. **Plan a job** (a bar, or manual cuts). The safety controller won't start without one.
2. **Pre-start checklist for that job** - tick every item and confirm (table and scrap tray
   cleared, fence/gate, walk-round, extraction, E-stop test, screens + PPE, extinguisher, magnet).
   **Every job needs its own checklist**: when a job finishes (or one that ran is swapped for
   another) the checklist is cleared, because the cell has changed - parts on the outfeed
   table, offcuts in the tray, someone may have gone in.
3. **Reset** (blue lamp blinking = reset needed). Refused until every cause is gone.
4. **Start** (or Run on the Machine tab). Green lamp = running at full speed; amber = reduced
   speed or paused; red = stopped.
5. **Job finished**: the screen asks what next - *Next bar*, *Run this job again*, *Clear the
   job* (deletes its parts / manual cuts and its plan) or *Keep it*. Saved jobs can be deleted on
   the Parts tab. A job can't be swapped or cleared while the machine runs.
6. Any stop latches. Find the cause, clear it, **Reset**, then **Start**.
7. Teaching or checking inside the fence: **Manual** mode - 250 mm/s and hold-to-run.
8. Maintenance: **Maintenance** mode + isolate + padlock (LOTO). After maintenance, the
   checklist must be confirmed again.

Every event is written with a time stamp to `logs/safety_log.jsonl` (and shown on the Safety tab).

## 5. Starter risk assessment (BS EN ISO 12100 style - complete it for your own cell)

| Hazard | Who | Measures in the design | Still to do on a real machine |
|---|---|---|---|
| Crushing / impact by gantry and arms | operator, maintenance | fence, interlocked gate, light curtain, E-stops, manual reduced speed, hold-to-run | safety PLC, validated PL, guard locking, stopping-time measurement |
| Plasma arc - burns, UV, noise | operator | torch only cuts while extraction runs; cell fenced | arc screens, PPE, noise assessment |
| Fume (carcinogenic) | everyone nearby | extraction interlock | LEV design, testing, 14-month examination, air monitoring |
| Falling part from the magnet | operator | 500 kg limit, part lifted only 250 mm, nobody in the cell in Auto | fail-safe magnet, LOLER examination, exclusion zone |
| Sharp edges, hot steel, sparks, fire | operator | offcuts drop into the skip; kerf shown hot in the 3D view | gloves, cooling time, fire extinguisher, no combustibles |
| Electric shock | maintenance | isolation in Maintenance mode | LOTO, BS 7671 installation, panel interlocks |
| Software fault | everyone | watchdogs, latching, separate reset/start, fail-safe wiring | **safety functions in certified hardware, independent of the software** |

## 6. Wiring the prototype's E-stop to the Jetson (optional)

For a physical demo you can wire a real E-stop so pressing it stops the 3D machine. This
**reports** the button to the software; it is not a safety circuit.

```
3.3 V (pin 1) ---[10 kOhm]---+--- GPIO pin (e.g. pin 11) on the Orin's 40-pin header
                             |
                     E-stop AUXILIARY NC contact
                             |
GND (pin 6) -----------------+
```
- Contact closed (button released) = pin reads 0 = healthy. Button pressed, wire cut or plug
  pulled = pin reads 1 = **E-STOP**. A broken wire can never hide a stop.
- Do the same for a gate switch (NC, closed when shut) and a light curtain's status relay.
- Reset button: normally-open push-button from the pin to GND (+ the same pull-up).
- Set the pins in `config/cell.toml` under `[gpio]`, `enabled = true`, and install
  `sudo apt install python3-jetson-gpio`. Check with `python3 -m beamcell.doctor`.
- On a real machine the E-stop's **main** contacts go to a safety relay that cuts motor
  power; only the auxiliary contact goes to the Jetson.

## 7. What is honestly still missing before anything real moves

- A safety PLC / safety relay design, with the PL calculated (e.g. with SISTEMA) and validated.
- Measured stopping times (they set the light curtain distance and the fence distances).
- A full risk assessment signed off by a competent person, and operator training records.
- If supplied or put into service as a machine: technical file, conformity assessment,
  Declaration of Conformity and UKCA marking.

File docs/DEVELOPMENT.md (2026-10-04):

# Developer notes

Steel Beam Cutting Cell - by Ravi Mahadeva. How the code fits together and how to change it safely.

A prototype 12 m structural-steel beam cutting cell (UK codes) with two overhead robot hands:
Cutter (plasma) and Handler (magnet). Python engine (`beamcell/`, stdlib + numpy only) serving
a three.js web app (`web/`). It runs on a Jetson Orin Nano (4 GB, see
`docs/JETSON_SPECS.md`) and is used from a browser. README.md has the folder map.

## Rules for changes
- No new Python dependencies (Jetson is offline-ish, 4 GB RAM). numpy only; OpenCV optional (camera).
  Exception: `beamcell/cad.py` uses CadQuery, PC-only and optional; its outputs (cad/*.step,
  web/models/*.glb + labels.json) are committed. After changing machine.py geometry or cad.py,
  run `python3 -m beamcell.cad` (scratch venv with `pip install cadquery`) and commit the outputs.
- Browser libraries go in `web/vendor/` (no CDN). three.js r160 is vendored.
- UK codes only (BS 4-1, BS EN 10056-1, BS EN 1090-2, BS EN 1993-1-8 + UK NA, SCI P358). Cite the
  source in every check message (`ref`).
- Units: mm for parts/sections/NC1, metres for the machine and the 3D scene. Machine axes: X along
  the 12 m bar, Y across (+Y = Cutter side), Z up.
- Keep plain-English UI text.

## How to check your work
- `python3 -m unittest discover -s tests -t .` (about 40 s) - must pass.
- `python3 tests/sweep_sections.py` - every cuttable section; must report 0 problems.
- Browser: `./start.sh --port 8099 &` then `node tests/ui_smoke.mjs http://localhost:8099`
  (needs playwright; CI runs it).
- Headless screenshots: Playwright + Chromium with `--use-gl=angle --use-angle=swiftshader`.
- Orin-like env for testing: Python 3.12, numpy 1.26.4, opencv-python-headless 4.6.0.66.

## Safety (most important)
- `beamcell/safety.py` is the only thing that decides motion; the browser asks it 5x/s
  (`/api/safety/tick`) and moves only when `may_move`, at `speed_factor`. Keep: latching stops,
  reset never restarts, start separate, checklist, watchdogs, Manual 250 mm/s hold-to-run.
- Never weaken a stop to make a demo easier. Tests in `tests/test_safety.py` and the browser test
  cover the procedures. Say plainly in docs/UI that software stops are not safety-rated.
- The AI advisor (`assistant.py`, via the `anthropic` SDK, off by default) is advisory only and
  must never get a path to move/reset/start anything.
- Settings live in `config/cell.toml` (tomllib); `python3 -m beamcell.doctor` checks a machine.

## Key design points
- Parts are described like NC1: per-face outlines (DSTV faces v/o/u/h) + holes + inner contours.
  Manual copes/mitres are converted to outlines (`Part.face_outline`). Cut paths = outline edges
  that aren't the plate's long edges (`Part.chains`).
- `planner.Placed.classify` maps a face point to a torch pass: D down, S side (+Y), P/N tilted
  45 deg. Arms hang upside down (`machine.FLIP`), elbow-up poses from `Hand.preference`.
- Cuts over 150 mm move the gantry with the torch (coordinated motion); torch is 400 mm long so
  wide UC flanges clear.
- `Plan._commit` keeps the bridges >= 1 m apart against everything the other hand has planned.
- The browser rebuilds a part's plates when its cut state changes (`geometry.partGroup`).
- The 3D machine is the CAD model: `scene.load()` reads web/models/cell.glb (static) and
  moving.glb (bridge/carriage/mast/link0..6 per hand, each modelled in its own frame; link k in
  DH frame k). The GLB root node turns Z-up into Y-up - `scene.js` undoes it. Every solid has a
  label (labels.json) shown on hover.
- Gravity: rollers at `machine.ROLLER_X`; loose pieces need two rollers (`supported_on_rollers`)
  or they fall into the scrap tray (`Plan._drop`, `fall_time`). Carried parts land on the table.
- Cut order (`planner._in_order`): start cut, holes along the bar by bolt group, cut-off.
- Manual cutting (`manual.py`): ManualBar placements with `keep` (rest of bar) / `scrap` flags.

## Status
Working in simulation, tested headless. The 1:10 prototype
(docs/PROTOTYPE.md, cad/prototype_1to10.step) needs: a FluidNC G-code streamer for the gantry
axes and maths for the 4-servo arms on the PCA9685 - not written yet. Part numbers come from
docs/prototype_bom.csv; cad.PROTO_PARTS maps each CAD solid to its line.

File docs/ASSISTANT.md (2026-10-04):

# "What's happening" and the optional AI advisor

## Is an LLM / VLM worth it here?

Short answer: **yes as an advisor, never as part of the safety system.**

| Job | Use AI? | Why |
|---|---|---|
| Stopping the machine, zones, interlocks | **No** | must be deterministic, fast (milliseconds) and certifiable. An AI model is none of these. The safety controller (`beamcell/safety.py`) is plain rules, and real machines put these functions in safety hardware. |
| Seeing people in the zones | YOLO (small vision model) | it's fast and good at "is there a person and where" - used as an **extra** layer (slow down / stop), never instead of the fence, gate and E-stops |
| "What's happening right now?" | **No AI needed** | the cell already knows exactly what each hand is doing, which part and face, and why it stopped. `situation()` turns those facts into plain sentences instantly - it's on the Machine tab. |
| Answering questions: "why did it stop?", "is this notch OK on a UB 457?", "what's on the camera?", "what should I check before reset?" | **Yes - this is where an LLM/VLM helps** | it explains in plain English from the same facts (and a camera picture). It's advisory: it can't move, start or reset anything. |

### Run it on the Jetson or in the cloud?
Your Orin Nano has **4 GB** of RAM shared by CPU and GPU, and the cell, the browser and YOLO
already use most of it. A vision-language model that can describe a camera picture usefully
needs several GB on its own, so running one **on the Jetson** would push everything else into
swap. The practical choice is to call a hosted model over the internet only when the operator
asks a question - nothing runs in the background, and nothing changes if the internet is down.

The advisor uses **Claude** (`claude-opus-5-5`, Anthropic's current default model) through the
official `anthropic` Python SDK, with low effort for quick answers. You can change the model and
effort in `config/cell.toml`.

## Switch it on

1. Install the SDK (once): `pip install --user anthropic`
2. Get an API key from the Anthropic Console and give it to the app:
   `export ANTHROPIC_API_KEY=sk-ant-...` (for the start-at-boot service, add
   `Environment=ANTHROPIC_API_KEY=...` to `deploy/beamcell.service`, or use an `EnvironmentFile`).
   Never commit the key to git.
3. In `config/cell.toml`: `[assistant]` `enabled = true`
4. Restart (`./start.sh`), then ask on the **Safety** tab. `python3 -m beamcell.doctor` checks the setup.

Each question sends: the live facts (safety state, stops, inputs, what each hand is doing,
the bar, camera zone status) and - if `send_camera = true` - the latest camera picture. Turn
`send_camera` off if pictures of people must not leave the site. Costs are per question
(a picture plus a short answer is a small amount - see Anthropic's pricing page).

## What it is told

The advisor's instructions (in `beamcell/assistant.py`) say: answer briefly from the facts,
say when it can't tell, and **never** advise bypassing, muting or defeating a stop, guard,
interlock, light curtain or E-stop, or entering the cell while it can move - if something
looks unsafe, press the E-stop and tell the supervisor.

## Later ideas (only if they earn their place)

- A YOLO model **trained on your own pictures** to find the beam's end and position on the
  bed, so the Cutter corrects for where the bar really lies (this is real value; it's vision,
  not an LLM).
- PPE detection (hi-vis, helmet) at the gate - needs a custom-trained YOLO.
- Reading drawings (PDF) to cross-check NC1 files - a good advisor task.

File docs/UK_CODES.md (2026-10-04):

# UK codes used by the cell

Everything is in millimetres and follows UK practice. The checks run every time you edit a
part, and every message names its source. Code rules live in `beamcell/uk_codes.py`; the
checks are in `Part.check()` in `beamcell/parts.py`.

## Sections

| Family | Standard | In the library |
|---|---|---|
| UB universal beams | BS 4-1:2005 | 107 |
| UC universal columns | BS 4-1:2005 | 46 |
| UBP universal bearing piles | BS 4-1:2005 | 17 |
| PFC parallel flange channels | BS 4-1:2005 | 16 |
| Equal angles | BS EN 10056-1 | 42 |
| Unequal angles | BS EN 10056-1 | 39 |
| SHS / RHS / CHS hot finished | BS EN 10210-2 | 387 |
| SHS / RHS / CHS cold formed | BS EN 10219-2 | 339 |

The sizes (h, b, tw, tf, r, r1, r2, mass, and the detailing values C, N, n) are the ones
published in the SCI/BCSA "Blue Book" (Steel for Life). They were taken from the open-source
`steelsnakes` package (GPL-2.0). Every outline is checked by a test: its area x 7850 kg/m³
matches the published mass. **Check sizes against the current Blue Book or mill data before
real fabrication.**

Hollow section corner radii: hot finished 1.5t outside / 1.0t inside (BS EN 10210-2);
cold formed 2t, 2.5t or 3t outside depending on t (BS EN 10219-2).

Additional sizes (made by the mills but not in BS 4-1) are marked with `*` in the library.

## Rules checked on every part

| Rule | Value | Source |
|---|---|---|
| Normal round hole for a bolt | M12, M14: d + 1; M16 to M24: d + 2; M27 and up: d + 3 | BS EN 1090-2 |
| Oversize hole | M12: +3, M16-M22: +4, M24: +6, M27+: +8 | BS EN 1090-2 |
| Short slot | normal hole + 4 / 6 / 8 / 10 mm longer | BS EN 1090-2 |
| Long slot | 1.5 x bolt diameter longer | BS EN 1090-2 |
| Holes may be thermally (plasma) cut | if the cut quality and hardness rules are met | BS EN 1090-2 |
| End distance e1, edge distance e2 | at least 1.2 d0 | BS EN 1993-1-8 Table 3.3 + UK NA |
| Spacing between holes | at least 2.2 d0 | BS EN 1993-1-8 Table 3.3 + UK NA |
| Holes clear of the web/flange root radius | hole edge outside tf + r | section geometry |
| Re-entrant corners (notches) rounded | at least 5 mm (10 mm used by default) | BS EN 1090-2 |
| Notch depth | at least tf + r so it clears the flange | UK detailing (Blue Book n) |
| Deep or long notches | depth over h/2 or length over h: warning for the engineer | SCI P358 |
| Default bolt | M20 grade 8.8 in 22 mm holes | SCI P358 / UK practice |
| Notch to clear a supporting beam | length N, depth n from that beam's Blue Book entry | Blue Book |
| Steel grades | S275JR/J0/J2, S355JR/J0/J2/K2 | BS EN 10025-2 |

d0 = hole diameter. These are minimums for fabrication checks; the connection design itself
(bolt numbers, plate sizes, notched-beam stability) is the engineer's job.

## Limits of this machine (not code rules)

| Limit | Value | Why |
|---|---|---|
| Smallest plasma hole | the plate thickness, and at least 10 mm | plasma can't make good holes smaller than the plate is thick |
| Shortest part | 150 mm | the Handler's magnet needs something to hold |
| Bottom-flange holes on I sections and channels | not possible | the torch can't reach under the top flange from above - use a drill line or turn the part |
| Hollow sections | not cut | they need a rotating chuck; they're in the library for drawings and 3D printing |
| Heaviest part the Handler lifts | 500 kg | heavier parts stay on the bed for the overhead crane |
| Stock lengths | 6, 8, 10, 12 m | the work area is 12 m |
| Gap between parts | 0 (shared cut) for two square ends, otherwise 20 mm | nesting |
| Mill-end trim | 10 mm | stock ends aren't square |

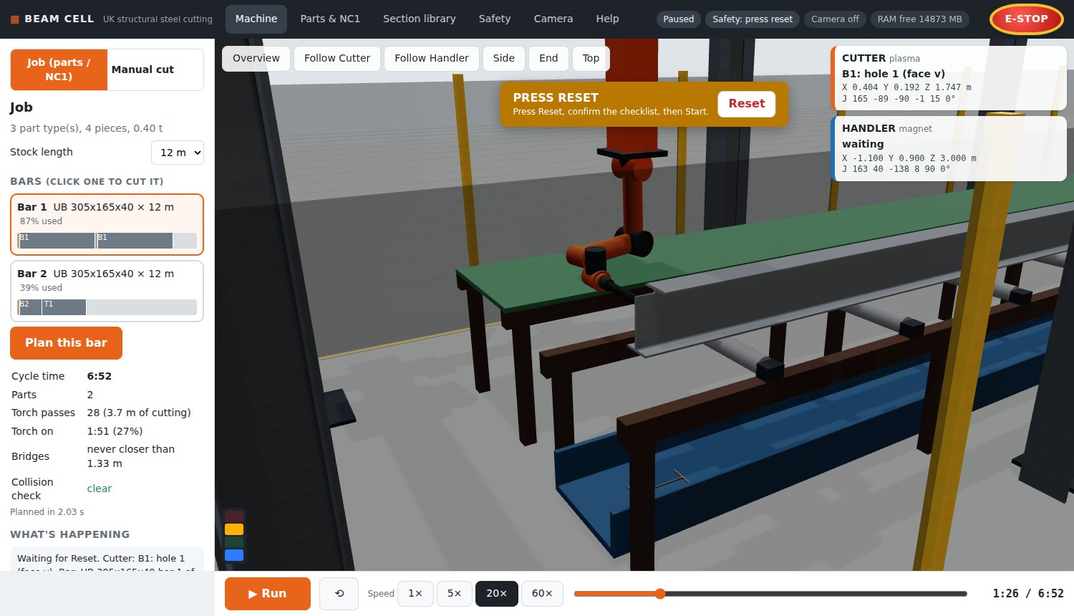
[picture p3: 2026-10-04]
docs/images/cutter.png

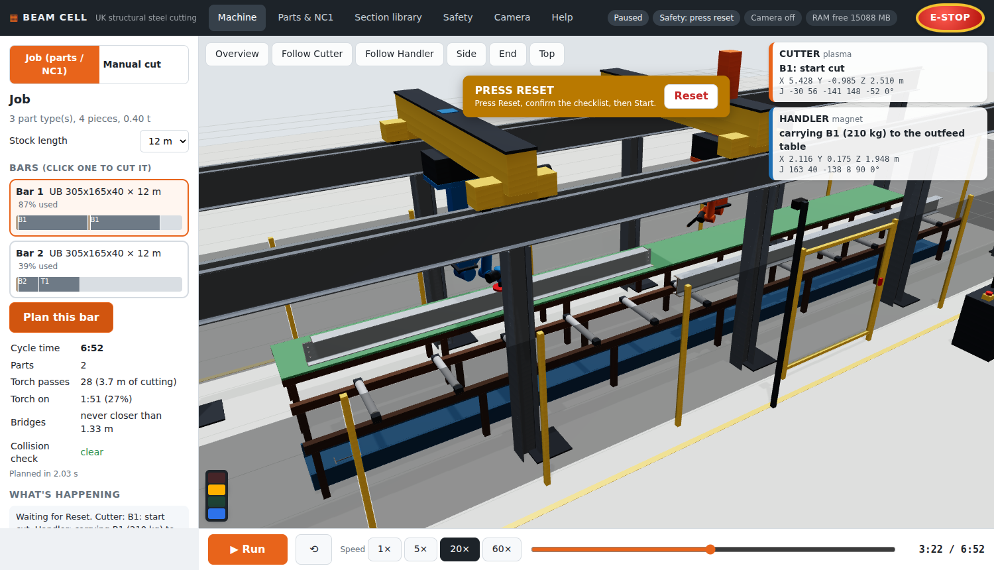
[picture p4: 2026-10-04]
docs/images/machine.png

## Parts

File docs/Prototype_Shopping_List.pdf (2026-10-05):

Steel Beam Cutting Cell - 1:10 prototype shopping list - Ravi Mahadeva | Page 1

# Prototype Shopping List

Steel Beam Cutting Cell - 1:10 desk-top prototype | Ravi Mahadeva | 05 October 2026

# TOTAL BUYING COST: about

£1,140

incl. VAT where known, before postage | with 10% spare for postage and price changes: about £1,260 | to get moving first
(stages 1-2): about £430
Stage | About
Stage 1 - Frame and bed | £130
Stage 2 - Motion and controller | £300
Stage 3 - Arms and tools | £100
Stage 4 - Cameras and sensors | £130
Stage 5 - Safety and enclosure | £360
Stage 6 - Electrical | £90
Consumables | £40
Total | about £1,140

Before you buy
- Prices are approximate (GBP, October 2026) and change - check each one before ordering.
- Every item has a link (blue): a product page where it was checked, otherwise that shop's search.
- Part numbers (P01 ...) are the same as the balloons in docs/Prototype_Assembly.pdf, the Prototype tab in the app and the CAD - so you can see where each part goes.
- You already have the Jetson Orin Nano; it is not in the total.
- Order the aluminium cut to size (lengths on the last page) - it saves a lot of work.
- Buy and wire the safety parts (stage 5) before any motor moves: the E-stop and safety relay must cut motor power. Have the mains wiring checked by a competent person.
- Cheapest way to start: stages 1 and 2 first (frame and moving gantry, about £430), then arms, cameras and the rest.
- A used Pilz PNOZ s3 is about £75 instead of £180 - but don't skip the safety relay or the E-stop.
- No real cutting on the prototype: the Cutter holds a pen that marks the cut lines.

Steel Beam Cutting Cell - 1:10 prototype shopping list - Ravi Mahadeva | Page 2

## Stage 1 - Frame and bed

OK | Part | Item | What to look for | Qty | Each | Line total | Where to buy (click)
P01 V-slot 20x20 aluminium cut to size - lengths in cad/prototype_cut_list.csv (frame, 9.5 m £8 £76 Ooznest (cut to size), Amazon UK Search ooznest.co.uk (https://ooznest.co.uk/?s=20x20mm+V-Slot+cut+to+size&post_type=product) extrusion bed rails, bridges, Z axes, camera post) the whole frame is 20x20; lengths come from the CAD model

P02 Corner brackets + M5 T-nuts + 30 cast 20-series corner brackets, 120 drop-in T-nuts, 1 kit £30 £30 Ooznest, Amazon UK M5 bolts M5x8 button heads Search ooznest.co.uk (https://ooznest.co.uk/?s=cast+corner+bracket+20+series&post_type=product)

P03 Rubber feet stick-on rubber feet 20 mm 4 £1 £4 Amazon UK Search amazon.co.uk (https://www.amazon.co.uk/s?k=rubber+feet+20mm+self+adhesive) stops it sliding on the desk

P04 Bed rollers 10 mm printed sleeves on 3 mm silver steel rod (50 mm), 2 6 £2 £12 Amazon UK, Simply Bearings x 623ZZ bearings each Search amazon.co.uk (https://www.amazon.co.uk/s?k=623ZZ+bearings+3mm) print the sleeves; buy rod and bearings

P05 Roller brackets (3D printed) PETG, clip on the 20x20 bed rails 12 £0 £0 print 3D print / make it filament counted under Consumables

P06 Bed riser blocks (3D printed) PETG blocks that hold the bed rails 60 mm above the base 6 £0 £0 print 3D print / make it filament counted under Consumables

P07 Outfeed table board 3 mm plywood strip 700 x 90 mm 1 £4 £4 builders' merchant, Amazon UK Search amazon.co.uk (https://www.amazon.co.uk/s?k=3mm+plywood+sheet)

P08 Outfeed table risers (3D printed) PETG 3 £0 £0 print 3D print / make it filament counted under Consumables

P09 Scrap tray (3D printed) 700 x 44 mm tray under the bed 1 £0 £0 print 3D print / make it filament counted under Consumables

Stage total | £126

Steel Beam Cutting Cell - 1:10 prototype shopping list - Ravi Mahadeva | Page 3

## Stage 2 - Motion and controller

OK | Part | Item | What to look for | Qty | Each | Line total | Where to buy (click)
P10 Mini V-wheel gantry plate kits 20-series mini gantry plate + 4 mini V-wheels (625 6 £12 £72 Ooznest Search ooznest.co.uk (https://ooznest.co.uk/?s=mini+V-wheel+gantry+plate&post_type=product) bearings) + eccentric spacers 2 per bridge end x 2 bridges + 1 per carriage x 2

P11 NEMA 17 stepper motor 1.5-2 A, 40 mm body, 5 mm shaft (a NEMA 14 is lighter if 4 £12 £48 Ooznest, StepperOnline you prefer) Search omc-stepperonline.com (https://www.omc-stepperonline.com/search?search=nema+17+stepper+motor+40mm) X (one per bridge) and Y (one per carriage)

P12 NEMA 17 with integrated T8 T8 x 2 mm lead, 150 mm screw, with brass nut 2 £22 £44 StepperOnline, Amazon UK Search omc-stepperonline.com (https://www.omc-stepperonline.com/search?search=nema+17+lead+screw+T8+150mm) lead screw Z axes

P13 Z motor bracket (3D printed) PETG shelf on top of the carriage plate, holds the Z and Y 2 £0 £0 print 3D print / make it motors filament counted under Consumables

P14 Lead-screw nut block (3D PETG block with the brass T8 nut, fixed to the Z axis 2 £0 £0 print printed) 3D print / make it filament counted under Consumables

P15 GT2 belt 6 mm 5 m (2 per bridge along the rails, 1 per carriage) 1 £8 £8 Ooznest Search ooznest.co.uk (https://ooznest.co.uk/?s=GT2+belt+6mm&post_type=product)

P16 GT2 16T pulleys + idlers 4 x 16T 5 mm bore (cross shafts), 2 x 16T (Y), 8 idlers 1 set £20 £20 Ooznest, Amazon UK Search ooznest.co.uk (https://ooznest.co.uk/?s=GT2+pulley+16+tooth&post_type=product)

P17 5 mm cross shafts + bearings 2 x 360 mm 5 mm silver steel, 4 x 625ZZ in printed blocks, 1 set £12 £12 Amazon UK, Simply Bearings 2 x 5-5 mm couplers Search amazon.co.uk (https://www.amazon.co.uk/s?k=5mm+linear+shaft+400mm) one motor drives both rails of a bridge

P18 Home / limit switches mechanical microswitch with lever, NC wiring 8 £1.50 £12 Amazon UK Search amazon.co.uk (https://www.amazon.co.uk/s?k=micro+limit+switch+lever+pack) one per axis + 2 spare

P19 FluidNC 6-axis CNC controller 6 driver sockets, USB to the Jetson (e.g. Elecrow / Bart 1 £40 £40 Elecrow, Tindie Open product page (https://www.elecrow.com/6x-cnc-controller-for-fluidnc.html) (ESP32) Dring 6x CNC Controller) flash once from the web installer - no programming

P20 TMC2209 stepper driver StepStick format 6 £5 £30 Amazon UK, Ooznest modules Search amazon.co.uk (https://www.amazon.co.uk/s?k=TMC2209+stepper+driver+stepstick) quiet; one per axis

P21 Motor cable + drag chain 5 m 4-core 0.25 mm2, 1 m 7x7 drag chain 1 set £15 £15 Amazon UK Search amazon.co.uk (https://www.amazon.co.uk/s?k=4+core+cable+0.25mm+drag+chain+7x7)

Stage total | £301

Steel Beam Cutting Cell - 1:10 prototype shopping list - Ravi Mahadeva | Page 4

## Stage 3 - Arms and tools

OK | Part | Item | What to look for | Qty | Each | Line total | Where to buy (click)
P22 MeArm-type 4-servo arm kit small 4-servo arm with MG90S metal-gear micro servos 2 £37 £74 Cool Components, Kitronik Open product page (https://coolcomponents.co.uk/collections/kits/robotic-arm) (reach ~150 mm); swap the gripper for the pen / magnet about £37 each (MeArm pocket-sized kit)

P23 Arm mount plate (3D printed) PETG plate: bolts the arm base under the Z axis 2 £0 £0 print 3D print / make it filament counted under Consumables

P24 PCA9685 16-channel servo I2C - wired straight to the Jetson's 40-pin header (pins 3 / 1 £6 £6 Amazon UK, kunkune board 5), drives all 8 servos Open product page (https://kunkune.co.uk/?p=11021) no extra controller needed for the arms

P25 5 V power supply for the servos Mean Well LRS-35-5 (5 V 7 A) - servos and magnet 1 £12 £12 RS, Farnell Search rs-online.com (https://uk.rs-online.com/web/c/?searchTerm=Mean+Well+LRS-35-5)

P26 Cutter 'torch' for the prototype fine-liner pen in a sprung 3D-printed holder (marks every 1 £2 £2 print 3D print / make it (pen holder) cut line on the model beam) no real cutting on the prototype: see docs/PROTOTYPE.md

P27 Handler magnet 5 V 20 mm lifting electromagnet (~2.5 kg hold) + MOSFET 1 £8 £8 Amazon UK module + flyback diode Search amazon.co.uk (https://www.amazon.co.uk/s?k=5V+electromagnet+20mm+lifting) switch it from a FluidNC output

P28 Model beams (3D printed) UB 305x165 at 1:10 (30 x 16 mm), 500 mm long, with steel 4 £0 £0 print 3D print / make it tape on the top flange the magnet needs steel to grip; filament counted under Consumables

Stage total | £102

Steel Beam Cutting Cell - 1:10 prototype shopping list - Ravi Mahadeva | Page 5

## Stage 4 - Cameras and sensors

OK | Part | Item | What to look for | Qty | Each | Line total | Where to buy (click)
P29 USB wide-angle camera (safety 1080p UVC, 90-120 deg view (e.g. Logitech C920/C922 or 1 £50 £50 Amazon UK, Pimoroni Search amazon.co.uk (https://www.amazon.co.uk/s?k=Logitech+C920+webcam) zone) an Arducam USB wide-angle) plug and play on the Jetson; YOLO watches the cell

P30 CSI camera (close-up of the Arducam IMX219 for Jetson Orin Nano (22-pin cable), 1 £25 £25 Arducam, RobotShop UK Cutter) wide-angle lens Open product page (https://www.arducam.com/arducam-imx219-pdaf-cdaf-autofocus-camera-module-with-case-for-raspberry-pi-nvidiar-jetson-orin-series.html) optional; checks the marked lines

P31 Powered USB 3 hub 4-port, own power supply 1 £20 £20 Amazon UK Search amazon.co.uk (https://www.amazon.co.uk/s?k=powered+USB+3.0+hub+4+port) controller + camera (+ spare)

P48 VL53L1X time-of-flight distance I2C breakout, up to 4 m - the datum sensor: finds where the 1 £12 £12 Pimoroni, The Pi Hut Search shop.pimoroni.com (https://shop.pimoroni.com/search?q=VL53L1X) sensor model beam starts on the Jetson's I2C with the PCA9685

P49 Pen touch-off micro-switch micro-switch with roller lever, on the sprung pen holder -2 £1.50 £3 Amazon UK, CPC finds the beam surface (the prototype's initial height Search amazon.co.uk (https://www.amazon.co.uk/s?k=micro+switch+roller+lever) sensing) one spare

P50 Load cell 1 kg + HX711 bar load cell 1 kg with HX711 amplifier - between the 1 £7 £7 Amazon UK, The Pi Hut Handler's wrist and magnet: weighs the part (slipping, Search amazon.co.uk (https://www.amazon.co.uk/s?k=load+cell+1kg+HX711) wrong part, not cut free)

P51 INA219 current sensor I2C current sensor in the magnet supply - checks the 1 £5 £5 Pimoroni, Amazon UK Search amazon.co.uk (https://www.amazon.co.uk/s?k=INA219+current+sensor) magnet is really on not drawn (wiring, inside the box)

P52 IR flame sensor module IR flame sensor with digital output - demonstrates the fire 1 £3 £3 Amazon UK detector Search amazon.co.uk (https://www.amazon.co.uk/s?k=IR+flame+sensor+module) NOT a certified fire detector - demo only

P53 Line laser module (Class 2) 650 nm line laser, Class 1 or 2 (1 mW or less) - with 1 £6 £6 Amazon UK Search amazon.co.uk (https://www.amazon.co.uk/s?k=line+laser+module+650nm+1mW) camera 2 it shows the beam's real profile never look into the beam; Class 2 or below only

Stage total | £131

Steel Beam Cutting Cell - 1:10 prototype shopping list - Ravi Mahadeva | Page 6

## Stage 5 - Safety and enclosure

OK | Part | Item | What to look for | Qty | Each | Line total | Where to buy (click)
P32 Emergency stop station yellow box, red 40 mm mushroom, turn to release, 2 NC 1 £42 £42 RS, Farnell, TME Search rs-online.com (https://uk.rs-online.com/web/c/?searchTerm=XALK178) contacts (e.g. Schneider Harmony XALK178 family) BS EN ISO 13850; NC contacts to the safety relay - add an NO/NC block for the Jetson

P33 Safety relay Pilz PNOZ s3 24 V DC (dual channel, manual reset) or 1 £180 £180 RS, Farnell (new) / ~£75 used Search farnell.com (https://uk.farnell.com/search?st=PNOZ+s3+751103) equivalent cuts the 24 V motor and 5 V servo supplies - this is how a real machine does it

P34 Door interlock switch non-contact coded magnetic safety switch, NC (e.g. Pilz 1 £60 £60 RS, Farnell Search rs-online.com (https://uk.rs-online.com/web/c/?searchTerm=non+contact+safety+switch+coded) PSEN or Schmersal BNS) BS EN ISO 14119; wired into the safety relay

P35 Reset push button 22 mm blue illuminated, 1 NO 1 £8 £8 RS, Amazon UK Search rs-online.com (https://uk.rs-online.com/web/c/?searchTerm=22mm+blue+illuminated+push+button) outside the enclosure with a view inside

P36 Stack light 24 V mini LED tower, red / amber / green 1 £15 £15 Amazon UK Search amazon.co.uk (https://www.amazon.co.uk/s?k=24V+mini+LED+stack+light+3+colour) driven by the Jetson through a relay module

P37 4-channel relay module 3.3 V logic input, 24 V contacts 1 £8 £8 Amazon UK (opto-isolated) Search amazon.co.uk (https://www.amazon.co.uk/s?k=4+channel+relay+module+optocoupler+3.3V) stack light and magnet

P38 IR break-beam sensor pair 5 mm IR break-beam (demonstrates the light-curtain input) 2 £6 £12 Pimoroni, The Pi Hut Search thepihut.com (https://thepihut.com/search?q=IR+break+beam+sensor) one pair demonstrates the light curtain, one is the bar-present photo-eye - NOT a safety light curtain

P39 Polycarbonate sheet 2 mm front door, ends and lid (~0.6 m2) - polycarbonate, not 0.6 m2 £35 £21 plastics stockist, Amazon UK Search amazon.co.uk (https://www.amazon.co.uk/s?k=2mm+polycarbonate+sheet+clear) acrylic (acrylic shatters)

P40 Hinges + handle 2 small hinges, 1 handle (20-series) 1 set £12 £12 Ooznest, Amazon UK Search ooznest.co.uk (https://ooznest.co.uk/?s=hinge+20+series&post_type=product)

Stage total | £358

Steel Beam Cutting Cell - 1:10 prototype shopping list - Ravi Mahadeva | Page 7

## Stage 6 - Electrical

OK | Part | Item | What to look for | Qty | Each | Line total | Where to buy (click)
P41 24 V power supply Mean Well LRS-100-24 (24 V 4.5 A) - motors, controller, 1 £14 £14 RS, Farnell Search rs-online.com (https://uk.rs-online.com/web/c/?searchTerm=Mean+Well+LRS-100-24) safety circuit

P42 IEC mains inlet with switch and panel mount, 3 A fuse 1 £8 £8 RS, Farnell Search rs-online.com (https://uk.rs-online.com/web/c/?searchTerm=IEC+inlet+switch+fuse) fuse have the mains side checked by a competent person

P43 DIN rail + terminals + fuse short 35 mm DIN rail, 12 terminals, 3 x 5x20 fuse holders 1 set £20 £20 RS, Farnell Search rs-online.com (https://uk.rs-online.com/web/c/?searchTerm=DIN+rail+terminal+block+fuse+holder) holders

P44 Control box ABS enclosure ~200 x 160 x 110 with cable glands 1 £20 £20 RS, CPC Search rs-online.com (https://uk.rs-online.com/web/c/?searchTerm=ABS+enclosure+200x160) holds the Jetson too

P45 Wire + ferrules + crimp tool 0.5 and 0.75 mm2 flexible, ferrule kit 1 set £25 £25 Amazon UK, CPC Search amazon.co.uk (https://www.amazon.co.uk/s?k=ferrule+crimp+tool+kit)

P46 Jetson Orin Nano Super (4 GB) you already have it - docs/JETSON_SPECS.md 1 £0 £0 -3D print / make it runs the app, YOLO, the planner and the arms

| | | Stage total | | | £87

## Consumables

OK | Part | Item | What to look for | Qty | Each | Line total | Where to buy (click)
| P47 | PETG and PLA filament | 1 kg each brackets, risers, tray, model beams, arm parts | 2 | £20 | £40 | Amazon UK, 3DJake Search amazon.co.uk (https://www.amazon.co.uk/s?k=PETG+filament+1kg+1.75mm)
| | | Stage total | | | £40

Steel Beam Cutting Cell - 1:10 prototype shopping list - Ravi Mahadeva | Page 8

## Aluminium cut list (order cut to size)

OK | Profile | Length (mm) | Quantity | Used for
| 20x20 V-slot | 200 | 2 | Z axis
| 20x20 V-slot | 280 | 4 | cross member
| 20x20 V-slot | 300 | 6 | upright
| 20x20 V-slot | 340 | 2 | bridge
| 20x20 V-slot | 390 | 1 | camera post
| 20x20 V-slot | 700 | 2 | bed rail
| 20x20 V-slot | 900 | 2 | base rail
| 20x20 V-slot | 900 | 2 | top rail

The lengths come from the CAD model (cad/prototype_1to10.step). The build steps, the safety wiring and why each part was chosen are in docs/PROTOTYPE.md.

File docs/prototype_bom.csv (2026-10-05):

part_no | stage | category | item | specification / what to look for | qty | approx_gbp_each | where (UK) | notes | link
P01 | 1 | Frame | V-slot 20x20 aluminium extrusion | cut to size - lengths in cad/prototype_cut_list.csv (frame, bed rails, bridges, Z axes, camera post) | 9.5 m | 8 | Ooznest (cut to size), Amazon UK | the whole frame is 20x20; lengths come from the CAD model | https://ooznest.co.uk/?s=20x20mm+V-Slot+cut+to+size&post_type=product
P02 | 1 | Frame | Corner brackets + M5 T-nuts + M5 bolts | 30 cast 20-series corner brackets, 120 drop-in T-nuts, M5x8 button heads | 1 kit | 30 | Ooznest, Amazon UK |  | https://ooznest.co.uk/?s=cast+corner+bracket+20+series&post_type=product
P03 | 1 | Frame | Rubber feet | stick-on rubber feet 20 mm | 4 | 1 | Amazon UK | stops it sliding on the desk | https://www.amazon.co.uk/s?k=rubber+feet+20mm+self+adhesive
P04 | 1 | Bed | Bed rollers | 10 mm printed sleeves on 3 mm silver steel rod (50 mm), 2 x 623ZZ bearings each | 6 | 2 | Amazon UK, Simply Bearings | print the sleeves; buy rod and bearings | https://www.amazon.co.uk/s?k=623ZZ+bearings+3mm
P05 | 1 | Bed | Roller brackets (3D printed) | PETG, clip on the 20x20 bed rails | 12 | 0 | print | filament counted under Consumables
P06 | 1 | Bed | Bed riser blocks (3D printed) | PETG blocks that hold the bed rails 60 mm above the base | 6 | 0 | print | filament counted under Consumables
P07 | 1 | Bed | Outfeed table board | 3 mm plywood strip 700 x 90 mm | 1 | 4 | builders' merchant, Amazon UK |  | https://www.amazon.co.uk/s?k=3mm+plywood+sheet
P08 | 1 | Bed | Outfeed table risers (3D printed) | PETG | 3 | 0 | print | filament counted under Consumables
P09 | 1 | Bed | Scrap tray (3D printed) | 700 x 44 mm tray under the bed | 1 | 0 | print | filament counted under Consumables
P10 | 2 | Motion | Mini V-wheel gantry plate kits | 20-series mini gantry plate + 4 mini V-wheels (625 bearings) + eccentric spacers | 6 | 12 | Ooznest | 2 per bridge end x 2 bridges + 1 per carriage x 2 | https://ooznest.co.uk/?s=mini+V-wheel+gantry+plate&post_type=product
P11 | 2 | Motion | NEMA 17 stepper motor | 1.5-2 A, 40 mm body, 5 mm shaft (a NEMA 14 is lighter if you prefer) | 4 | 12 | Ooznest, StepperOnline | X (one per bridge) and Y (one per carriage) | https://www.omc-stepperonline.com/search?search=nema+17+stepper+motor+40mm
P12 | 2 | Motion | NEMA 17 with integrated T8 lead screw | T8 x 2 mm lead, 150 mm screw, with brass nut | 2 | 22 | StepperOnline, Amazon UK | Z axes | https://www.omc-stepperonline.com/search?search=nema+17+lead+screw+T8+150mm
P13 | 2 | Motion | Z motor bracket (3D printed) | PETG shelf on top of the carriage plate, holds the Z and Y motors | 2 | 0 | print | filament counted under Consumables
P14 | 2 | Motion | Lead-screw nut block (3D printed) | PETG block with the brass T8 nut, fixed to the Z axis | 2 | 0 | print | filament counted under Consumables
P15 | 2 | Motion | GT2 belt 6 mm | 5 m (2 per bridge along the rails, 1 per carriage) | 1 | 8 | Ooznest |  | https://ooznest.co.uk/?s=GT2+belt+6mm&post_type=product
P16 | 2 | Motion | GT2 16T pulleys + idlers | 4 x 16T 5 mm bore (cross shafts), 2 x 16T (Y), 8 idlers | 1 set | 20 | Ooznest, Amazon UK |  | https://ooznest.co.uk/?s=GT2+pulley+16+tooth&post_type=product
P17 | 2 | Motion | 5 mm cross shafts + bearings | 2 x 360 mm 5 mm silver steel, 4 x 625ZZ in printed blocks, 2 x 5-5 mm couplers | 1 set | 12 | Amazon UK, Simply Bearings | one motor drives both rails of a bridge | https://www.amazon.co.uk/s?k=5mm+linear+shaft+400mm
P18 | 2 | Motion | Home / limit switches | mechanical microswitch with lever, NC wiring | 8 | 1.5 | Amazon UK | one per axis + 2 spare | https://www.amazon.co.uk/s?k=micro+limit+switch+lever+pack
P19 | 2 | Controller | FluidNC 6-axis CNC controller (ESP32) | 6 driver sockets, USB to the Jetson (e.g. Elecrow / Bart Dring 6x CNC Controller) | 1 | 40 | Elecrow, Tindie | flash once from the web installer - no programming | https://www.elecrow.com/6x-cnc-controller-for-fluidnc.html
P20 | 2 | Controller | TMC2209 stepper driver modules | StepStick format | 6 | 5 | Amazon UK, Ooznest | quiet; one per axis | https://www.amazon.co.uk/s?k=TMC2209+stepper+driver+stepstick
P21 | 2 | Controller | Motor cable + drag chain | 5 m 4-core 0.25 mm2, 1 m 7x7 drag chain | 1 set | 15 | Amazon UK |  | https://www.amazon.co.uk/s?k=4+core+cable+0.25mm+drag+chain+7x7
P22 | 3 | Arms | MeArm-type 4-servo arm kit | small 4-servo arm with MG90S metal-gear micro servos (reach ~150 mm); swap the gripper for the pen / magnet | 2 | 37 | Cool Components, Kitronik | about £37 each (MeArm pocket-sized kit) | https://coolcomponents.co.uk/collections/kits/robotic-arm
P23 | 3 | Arms | Arm mount plate (3D printed) | PETG plate: bolts the arm base under the Z axis | 2 | 0 | print | filament counted under Consumables
P24 | 3 | Arms | PCA9685 16-channel servo board | I2C - wired straight to the Jetson's 40-pin header (pins 3 / 5), drives all 8 servos | 1 | 6 | Amazon UK, kunkune | no extra controller needed for the arms | https://kunkune.co.uk/?p=11021
P25 | 3 | Arms | 5 V power supply for the servos | Mean Well LRS-35-5 (5 V 7 A) - servos and magnet | 1 | 12 | RS, Farnell |  | https://uk.rs-online.com/web/c/?searchTerm=Mean+Well+LRS-35-5
P26 | 3 | Tools | Cutter 'torch' for the prototype (pen holder) | fine-liner pen in a sprung 3D-printed holder (marks every cut line on the model beam) | 1 | 2 | print | no real cutting on the prototype: see docs/PROTOTYPE.md
P27 | 3 | Tools | Handler magnet | 5 V 20 mm lifting electromagnet (~2.5 kg hold) + MOSFET module + flyback diode | 1 | 8 | Amazon UK | switch it from a FluidNC output | https://www.amazon.co.uk/s?k=5V+electromagnet+20mm+lifting
P28 | 3 | Tools | Model beams (3D printed) | UB 305x165 at 1:10 (30 x 16 mm), 500 mm long, with steel tape on the top flange | 4 | 0 | print | the magnet needs steel to grip; filament counted under Consumables
P29 | 4 | Vision | USB wide-angle camera (safety zone) | 1080p UVC, 90-120 deg view (e.g. Logitech C920/C922 or an Arducam USB wide-angle) | 1 | 50 | Amazon UK, Pimoroni | plug and play on the Jetson; YOLO watches the cell | https://www.amazon.co.uk/s?k=Logitech+C920+webcam
P30 | 4 | Vision | CSI camera (close-up of the Cutter) | Arducam IMX219 for Jetson Orin Nano (22-pin cable), wide-angle lens | 1 | 25 | Arducam, RobotShop UK | optional; checks the marked lines | https://www.arducam.com/arducam-imx219-pdaf-cdaf-autofocus-camera-module-with-case-for-raspberry-pi-nvidiar-jetson-orin-series.html
P31 | 4 | Vision | Powered USB 3 hub | 4-port, own power supply | 1 | 20 | Amazon UK | controller + camera (+ spare) | https://www.amazon.co.uk/s?k=powered+USB+3.0+hub+4+port
P32 | 5 | Safety | Emergency stop station | yellow box, red 40 mm mushroom, turn to release, 2 NC contacts (e.g. Schneider Harmony XALK178 family) | 1 | 42 | RS, Farnell, TME | BS EN ISO 13850; NC contacts to the safety relay - add an NO/NC block for the Jetson | https://uk.rs-online.com/web/c/?searchTerm=XALK178
P33 | 5 | Safety | Safety relay | Pilz PNOZ s3 24 V DC (dual channel, manual reset) or equivalent | 1 | 180 | RS, Farnell (new) / ~£75 used | cuts the 24 V motor and 5 V servo supplies - this is how a real machine does it | https://uk.farnell.com/search?st=PNOZ+s3+751103
P34 | 5 | Safety | Door interlock switch | non-contact coded magnetic safety switch, NC (e.g. Pilz PSEN or Schmersal BNS) | 1 | 60 | RS, Farnell | BS EN ISO 14119; wired into the safety relay | https://uk.rs-online.com/web/c/?searchTerm=non+contact+safety+switch+coded
P35 | 5 | Safety | Reset push button | 22 mm blue illuminated, 1 NO | 1 | 8 | RS, Amazon UK | outside the enclosure with a view inside | https://uk.rs-online.com/web/c/?searchTerm=22mm+blue+illuminated+push+button
P36 | 5 | Safety | Stack light | 24 V mini LED tower, red / amber / green | 1 | 15 | Amazon UK | driven by the Jetson through a relay module | https://www.amazon.co.uk/s?k=24V+mini+LED+stack+light+3+colour
P37 | 5 | Safety | 4-channel relay module (opto-isolated) | 3.3 V logic input, 24 V contacts | 1 | 8 | Amazon UK | stack light and magnet | https://www.amazon.co.uk/s?k=4+channel+relay+module+optocoupler+3.3V
P38 | 5 | Safety | IR break-beam sensor pair | 5 mm IR break-beam (demonstrates the light-curtain input) | 2 | 6 | Pimoroni, The Pi Hut | one pair demonstrates the light curtain, one is the bar-present photo-eye - NOT a safety light curtain | https://thepihut.com/search?q=IR+break+beam+sensor
P39 | 5 | Enclosure | Polycarbonate sheet 2 mm | front door, ends and lid (~0.6 m2) - polycarbonate, not acrylic (acrylic shatters) | 0.6 m2 | 35 | plastics stockist, Amazon UK |  | https://www.amazon.co.uk/s?k=2mm+polycarbonate+sheet+clear
P40 | 5 | Enclosure | Hinges + handle | 2 small hinges, 1 handle (20-series) | 1 set | 12 | Ooznest, Amazon UK |  | https://ooznest.co.uk/?s=hinge+20+series&post_type=product
P41 | 6 | Electrical | 24 V power supply | Mean Well LRS-100-24 (24 V 4.5 A) - motors, controller, safety circuit | 1 | 14 | RS, Farnell |  | https://uk.rs-online.com/web/c/?searchTerm=Mean+Well+LRS-100-24
P42 | 6 | Electrical | IEC mains inlet with switch and fuse | panel mount, 3 A fuse | 1 | 8 | RS, Farnell | have the mains side checked by a competent person | https://uk.rs-online.com/web/c/?searchTerm=IEC+inlet+switch+fuse
P43 | 6 | Electrical | DIN rail + terminals + fuse holders | short 35 mm DIN rail, 12 terminals, 3 x 5x20 fuse holders | 1 set | 20 | RS, Farnell |  | https://uk.rs-online.com/web/c/?searchTerm=DIN+rail+terminal+block+fuse+holder
P44 | 6 | Electrical | Control box | ABS enclosure ~200 x 160 x 110 with cable glands | 1 | 20 | RS, CPC | holds the Jetson too | https://uk.rs-online.com/web/c/?searchTerm=ABS+enclosure+200x160
P45 | 6 | Electrical | Wire + ferrules + crimp tool | 0.5 and 0.75 mm2 flexible, ferrule kit | 1 set | 25 | Amazon UK, CPC |  | https://www.amazon.co.uk/s?k=ferrule+crimp+tool+kit
P46 | 6 | Electrical | Jetson Orin Nano Super (4 GB) | you already have it - docs/JETSON_SPECS.md | 1 | 0 | - | runs the app, YOLO, the planner and the arms
P47 | 7 | Consumables | PETG and PLA filament | 1 kg each | 2 | 20 | Amazon UK, 3DJake | brackets, risers, tray, model beams, arm parts | https://www.amazon.co.uk/s?k=PETG+filament+1kg+1.75mm
P48 | 4 | Sensing | VL53L1X time-of-flight distance sensor | I2C breakout, up to 4 m - the datum sensor: finds where the model beam starts | 1 | 12 | Pimoroni, The Pi Hut | on the Jetson's I2C with the PCA9685 | https://shop.pimoroni.com/search?q=VL53L1X
P49 | 4 | Sensing | Pen touch-off micro-switch | micro-switch with roller lever, on the sprung pen holder - finds the beam surface (the prototype's initial height sensing) | 2 | 1.5 | Amazon UK, CPC | one spare | https://www.amazon.co.uk/s?k=micro+switch+roller+lever
P50 | 4 | Sensing | Load cell 1 kg + HX711 | bar load cell 1 kg with HX711 amplifier - between the Handler's wrist and magnet: weighs the part (slipping, wrong part, not cut free) | 1 | 7 | Amazon UK, The Pi Hut |  | https://www.amazon.co.uk/s?k=load+cell+1kg+HX711
P51 | 4 | Sensing | INA219 current sensor | I2C current sensor in the magnet supply - checks the magnet is really on | 1 | 5 | Pimoroni, Amazon UK | not drawn (wiring, inside the box) | https://www.amazon.co.uk/s?k=INA219+current+sensor
P52 | 4 | Sensing | IR flame sensor module | IR flame sensor with digital output - demonstrates the fire detector | 1 | 3 | Amazon UK | NOT a certified fire detector - demo only | https://www.amazon.co.uk/s?k=IR+flame+sensor+module
P53 | 4 | Sensing | Line laser module (Class 2) | 650 nm line laser, Class 1 or 2 (1 mW or less) - with camera 2 it shows the beam's real profile | 1 | 6 | Amazon UK | never look into the beam; Class 2 or below only | https://www.amazon.co.uk/s?k=line+laser+module+650nm+1mW

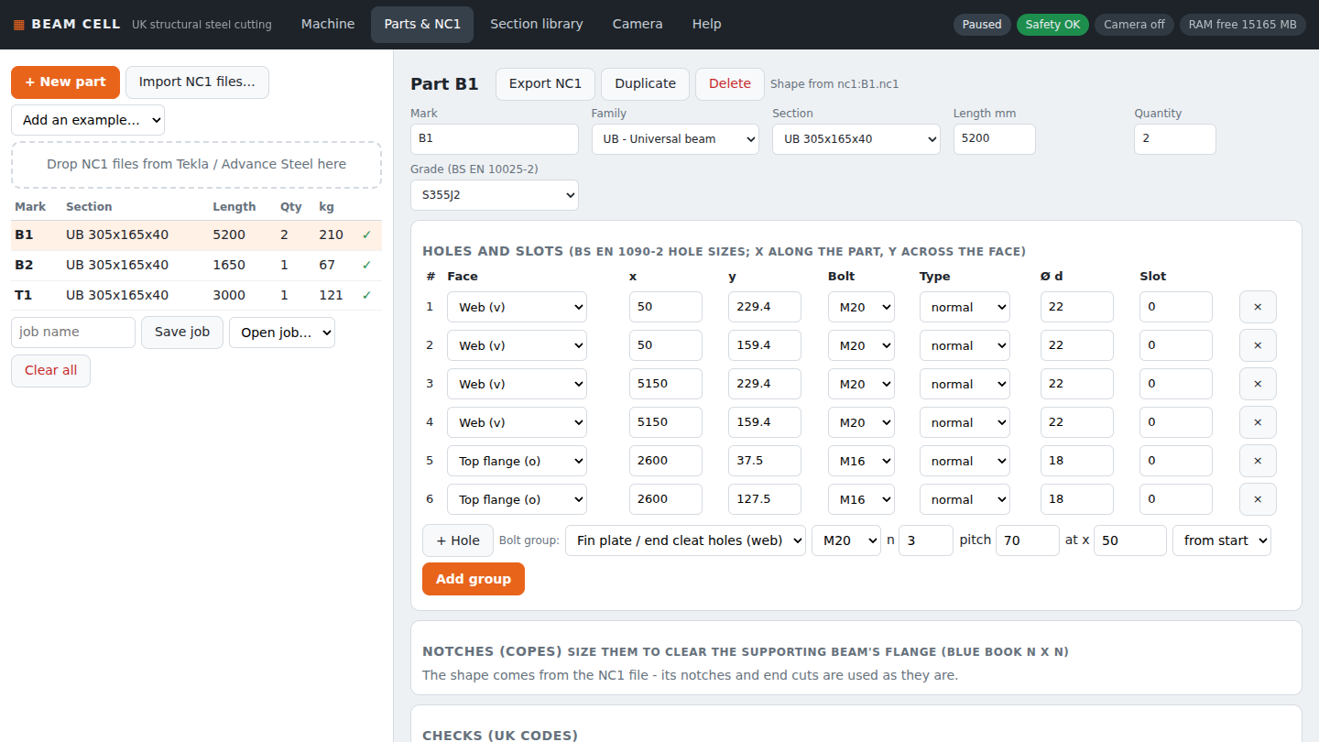
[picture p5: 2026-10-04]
docs/images/parts.png

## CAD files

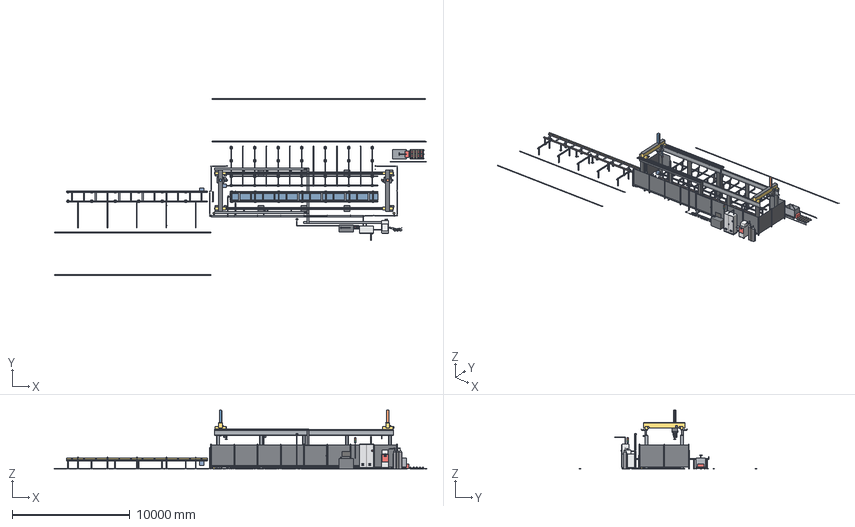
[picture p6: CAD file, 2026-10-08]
cad/beam_cell.step
31600.0 x 15050.0 x 5000.0 mm
runway_front
crane_rail_front
column_front
base_plate_front
column_front_2
base_plate_front_2
column_front_3
base_plate_front_3
column_front_4
base_plate_front_4
column_front_5
base_plate_front_5
runway_back
crane_rail_back
column_back
base_plate_back
column_back_2
base_plate_back_2
column_back_3
base_plate_back_3
column_back_4
base_plate_back_4
column_back_5
base_plate_back_5
bed_rail
bed_leg
bed_foot
anchor
anchor_2
anchor_3
anchor_4
bed_leg_2
bed_foot_2
anchor_5
anchor_6
anchor_7
anchor_8
bed_leg_3
bed_foot_3
anchor_9
anchor_10
anchor_11
anchor_12
bed_leg_4
bed_foot_4
anchor_13
anchor_14
anchor_15
anchor_16
bed_leg_5
bed_foot_5
anchor_17
anchor_18
anchor_19
anchor_20
bed_leg_6
bed_foot_6
anchor_21
anchor_22
anchor_23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

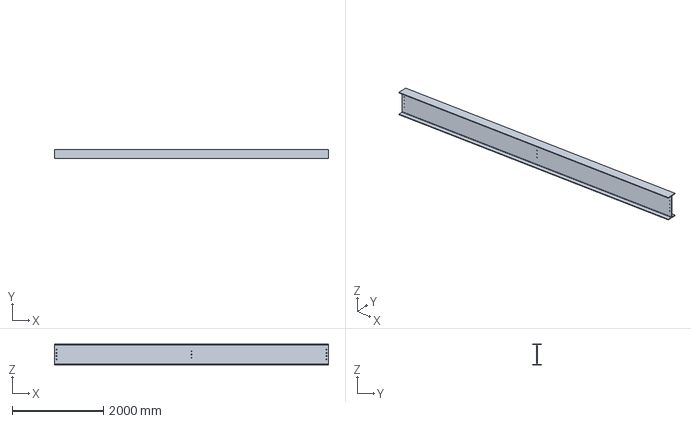
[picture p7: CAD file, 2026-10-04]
cad/parts/G1.step
6000.0 x 189.9 x 453.4 mm

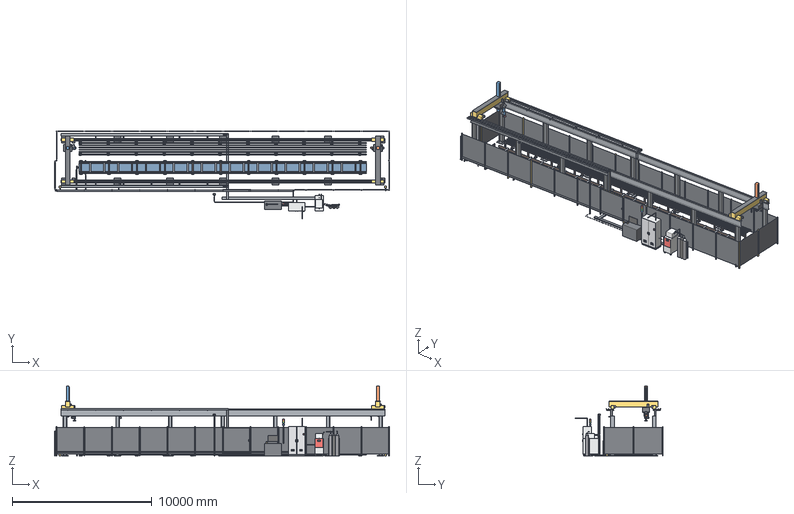
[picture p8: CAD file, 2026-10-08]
cad/beam_cell_20m.step
23980.0 x 6330.0 x 5000.0 mm
runway_front
crane_rail_front
column_front
base_plate_front
column_front_2
base_plate_front_2
column_front_3
base_plate_front_3
column_front_4
base_plate_front_4
column_front_5
base_plate_front_5
column_front_6
base_plate_front_6
column_front_7
base_plate_front_7
runway_back
crane_rail_back
column_back
base_plate_back
column_back_2
base_plate_back_2
column_back_3
base_plate_back_3
column_back_4
base_plate_back_4
column_back_5
base_plate_back_5
column_back_6
base_plate_back_6
column_back_7
base_plate_back_7
bed_rail
bed_leg
bed_foot
anchor
anchor_2
anchor_3
anchor_4
bed_leg_2
bed_foot_2
anchor_5
anchor_6
anchor_7
anchor_8
bed_leg_3
bed_foot_3
anchor_9
anchor_10
anchor_11
anchor_12
bed_leg_4
bed_foot_4
anchor_13
anchor_14
anchor_15
anchor_16
bed_leg_5
bed_foot_5
anchor_17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

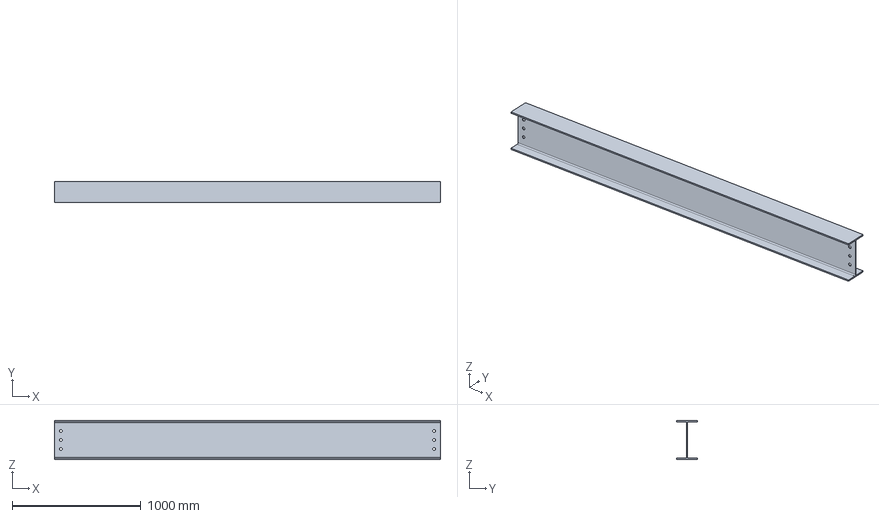
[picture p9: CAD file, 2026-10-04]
cad/parts/T1.step
3000.0 x 165.0 x 303.4 mm

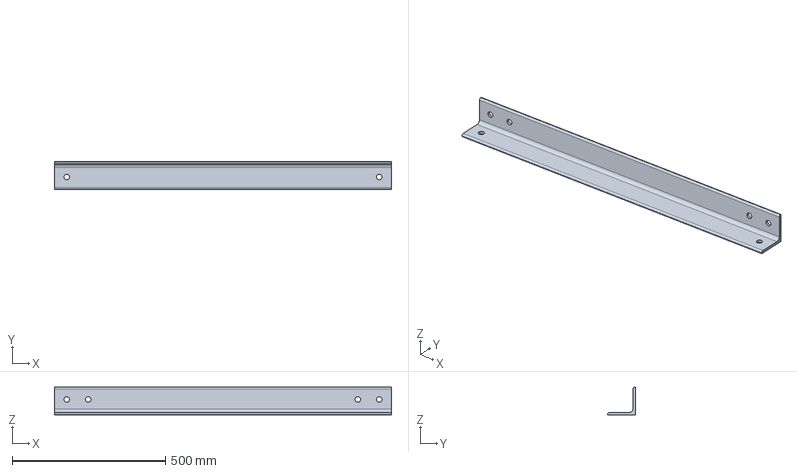
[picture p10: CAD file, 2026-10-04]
cad/parts/A1.step
1100.0 x 90.0 x 90.0 mm

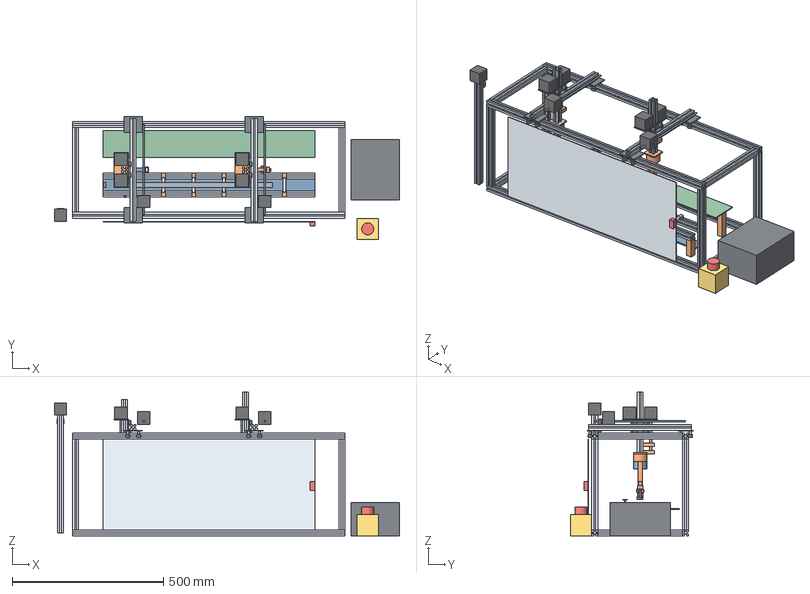
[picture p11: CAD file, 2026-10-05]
cad/prototype_1to10.step
1140.0 x 406.0 x 475.3 mm
P01-1 base_rail
P01-2 top_rail
P01-3 upright
P01-4 upright
P01-5 upright
P01-6 base_rail
P01-7 top_rail
P01-8 upright
P01-9 upright
P01-10 upright
P01-11 cross_member
P01-12 cross_member
P01-13 cross_member
P01-14 cross_member
P01-15 bed_rail
P06-1 bed_riser
P06-2 bed_riser
P06-3 bed_riser
P01-16 bed_rail
P06-4 bed_riser
P06-5 bed_riser
P06-6 bed_riser
P04-1 bed_roller
P05-1 bed_bracket
P05-2 bed_bracket
P04-2 bed_roller
P05-3 bed_bracket
P05-4 bed_bracket
P04-3 bed_roller
P05-5 bed_bracket
P05-6 bed_bracket
P04-4 bed_roller
P05-7 bed_bracket
P05-8 bed_bracket
P04-5 bed_roller
P05-9 bed_bracket
P05-10 bed_bracket
P04-6 bed_roller
P05-11 bed_bracket
P05-12 bed_bracket
P09-1 scrap_tray
P07-1 outfeed_table
P08-1 outfeed_riser
P08-2 outfeed_riser
P08-3 outfeed_riser
P28-1 model_beam
P01-17 bridge
P10-1 gantry_plate
P10-2 v_wheel
P10-3 wheel_spacer
P10-4 v_wheel
P10-5 wheel_spacer
P10-6 v_wheel
P10-7 wheel_spacer
P10-8 v_wheel
P10-9 wheel_spacer
P10-10 gantry_plate
P10-11 v_wheel
P10-12 wheel_spacer
P10-13 v_wheel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

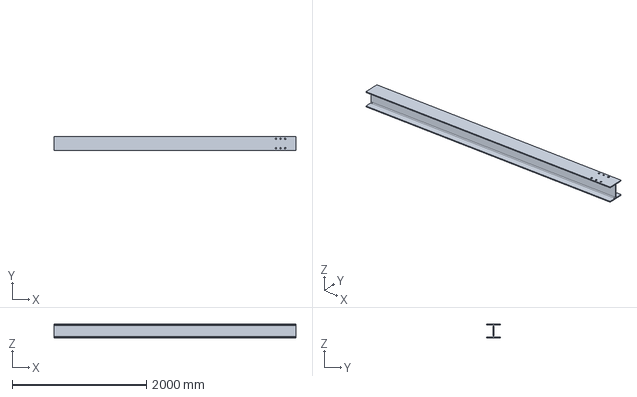
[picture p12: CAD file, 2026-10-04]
cad/parts/C1.step
3600.0 x 203.6 x 203.2 mm

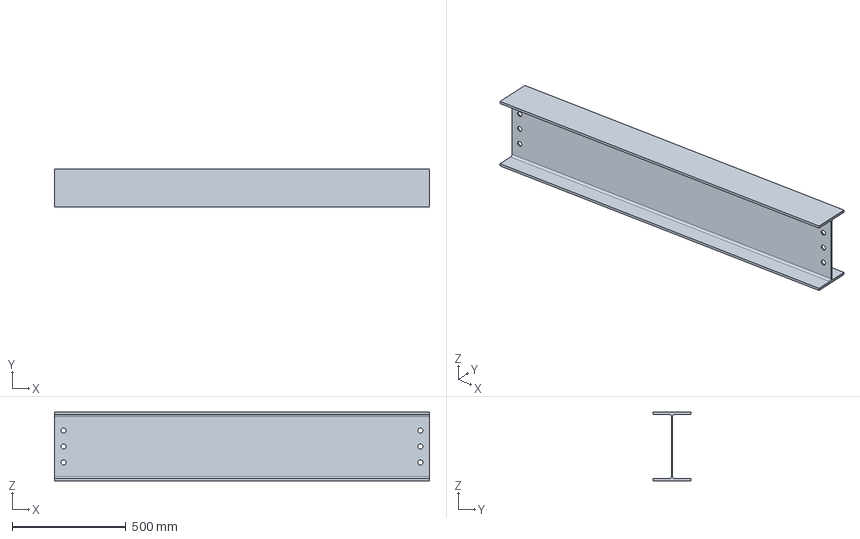
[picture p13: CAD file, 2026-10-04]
cad/parts/B2.step
1650.0 x 165.0 x 303.4 mm

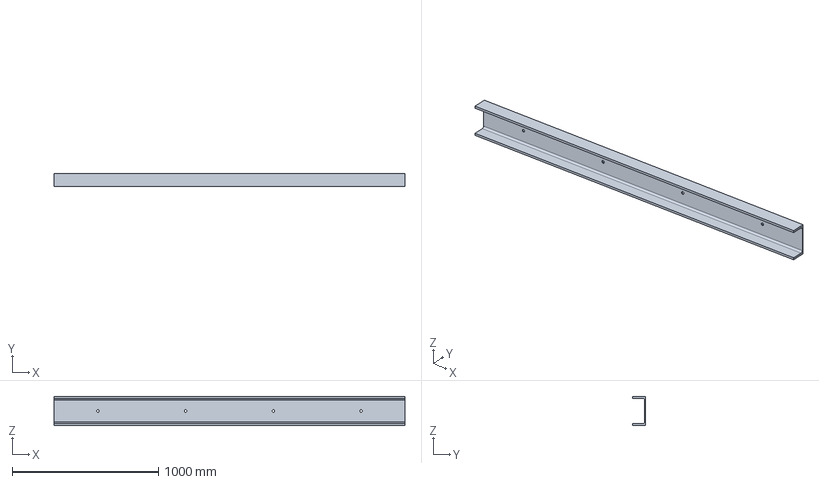
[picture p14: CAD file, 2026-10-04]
cad/parts/P1.step
2400.0 x 90.0 x 200.0 mm

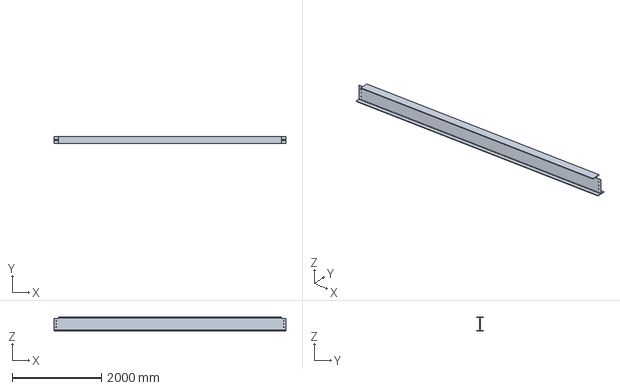
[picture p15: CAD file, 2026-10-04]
cad/parts/B1.step
5200.0 x 165.0 x 303.4 mm

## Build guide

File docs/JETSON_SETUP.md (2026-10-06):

# Running it on the Jetson Orin Nano

Your board (see `JETSON_SPECS.md`): Orin Nano Super, **4 GB RAM**, JetPack 7.2.1, Ubuntu
24.04, Python 3.12, numpy 1.26.4, OpenCV 4.6.0. **Nothing needs installing** - the server
uses only Python's standard library, numpy and (for the camera) OpenCV, and the 3D library
(three.js) is inside the repo.

## Check the Orin first

```
python3 -m beamcell.doctor --save
git add docs/SYSTEM_CHECK.md && git commit -m "System check" && git push
```
It lists what's ready and what's missing (camera, YOLO model, GPIO, memory...) with a plan, and
the saved report lets a cloud session see your exact setup.

## Start it

```
cd ~/steel-beam-cutting-cell
git pull
./start.sh
```

Open **http://localhost:8080** in Chromium on the Jetson. The terminal also prints an address
like `http://172.20.10.5:8080` - open that on a laptop, tablet or phone on the same Wi-Fi
for a demo (it's often smoother there, and it saves the Jetson's memory).

Stop it with **Ctrl+C**.

## Start automatically at boot

```
sudo cp deploy/beamcell.service /etc/systemd/system/
sudo systemctl daemon-reload
sudo systemctl enable --now beamcell
```

Check with `systemctl status beamcell`; read the log with `journalctl -u beamcell -f`.

## Full-screen demo (kiosk mode)

```
chromium-browser --kiosk --app=http://localhost:8080
```
(On some JetPack versions the command is `chromium`.) Press **Alt+F4** to leave.

## Memory: the Orin has only 4 GB

When you checked, only ~365 MB was free and swap was full. To keep it smooth:
- Close other programs (especially other browsers / old matplotlib windows).
- If the 3D view is slow: **Help → Use low graphics** (turns off shadows and smoothing).
- Or run the server on the Jetson and open the app on a laptop instead.
- The pill at the top right shows the Jetson's free memory, updated every 15 s.
- The camera only starts when you press *Start camera*; *Stop* frees its memory.

## Camera

| Camera | Choose |
|---|---|
| USB webcam | *USB camera 0* (or 1 if you have two) |
| Raspberry Pi / Arducam CSI camera on the Orin's ribbon connector | *Jetson CSI camera* (uses `nvarguscamerasrc`) |
| A recorded video, for a demo without a camera | *Video file...* and type its path |

Check a USB camera is seen with `ls /dev/video*`. A CSI camera can be tested with
`nvgstcapture-1.0`.

## Person and object detection (YOLO) - on the GPU

Three detectors, best first - the app uses the best one it finds:

| | Detector | Speed on the Orin Nano (estimate) | Finds |
|---|---|---|---|
| 1 | **YOLO on the GPU** (TensorRT engine, `models/*.engine`) | about 30+ pictures/s, CPU left free | people **and objects** |
| 2 | YOLO on the CPU (`models/*.onnx`, OpenCV DNN) | a few pictures/s, busy CPU | people and objects - **needs OpenCV 4.7 or newer**: the Jetson's OpenCV 4.6 can't run YOLOv8 / YOLO11, so on this board it's the GPU or HOG |
| 3 | HOG (built into OpenCV, no download) | slow, misses people side-on | people only |

### Set up YOLO on the GPU (once, about 15 minutes)

**1. Check TensorRT for Python is there** (it comes with JetPack):
```
python3 -c "import tensorrt; print(tensorrt.__version__)"
```
If that fails: `sudo apt install python3-libnvinfer` (or `sudo apt install nvidia-jetpack`).

**2. Get the model as ONNX** - on any PC with Python, not the Jetson (it has no PyTorch, and
it saves memory and download):
```
pip install ultralytics
yolo export model=yolo11n.pt format=onnx imgsz=640 opset=17
```
Copy `yolo11n.onnx` (about 10 MB) to `~/steel-beam-cutting-cell/models/` on the Jetson.
(Checked: this file finds the people and the bus in Ultralytics' test photo with the app's own
post-processing, the same as Ultralytics' reference results.)

**3. Build the GPU engine on the Jetson** (close the browser first - it needs memory):
```
cd ~/steel-beam-cutting-cell
tools/make_trt_engine.sh
```
It makes `models/yolo11n.engine` (5-10 minutes; FP16). An engine only works on the GPU and
TensorRT version it was built on - build it again after a JetPack upgrade.

**4. Use it:** restart the app, **Camera** tab, *Detector* "YOLO on the GPU (TensorRT)", Start camera.
The status line says which detector runs and how many pictures per second.
`python3 -m beamcell.doctor` shows the line "YOLO on the GPU (TensorRT)".

If the engine can't be loaded, the app says why and falls back to the CPU with the `.onnx` (if this
OpenCV can run it - it tries the model once when the camera starts), then to HOG.

**Licence note:** Ultralytics YOLO models (YOLO11, YOLOv8) are AGPL-3.0. That's fine for this
prototype and for research; selling a product that contains them needs an Ultralytics licence -
or a model under a permissive licence. The model files aren't kept in git.

## Camera zones

Three boxes on the camera picture (set them with the sliders, defaults in `config/cell.toml`):
- **Warning** (amber): someone's feet inside - the machine slows to 25%.
- **Danger** (red): protective stop, latched until the zone is clear **and** Reset is pressed.
- **Bed** (pink): YOLO objects lying on the roller bed - a bag, bottle, phone, tool... - are
  listed on the Camera tab. With `camera_object_stop = true` (`[safety]` in `config/cell.toml`)
  they also stop the machine (an OBJECT stop: the hands hold where they are). Leave it `false`
  until you have watched it for a while - YOLO knows everyday objects (COCO), not every tool, and
  a shadow or the steel itself must never stop a job. A model trained on your own photos of
  tools on the bed would do better later.

Set `require_camera = true` to stop the machine if the camera fails.
This is an extra layer only - see `SAFETY.md`.

## Real E-stop and buttons

You can wire a real E-stop, gate switch, light-curtain relay and reset button to the 40-pin
header - wiring and settings in `SAFETY.md` section 6.

## AI advisor (optional)

See `ASSISTANT.md` - it runs in the cloud only when you ask a question, because the Orin's
4 GB can't hold a vision-language model next to the cell.

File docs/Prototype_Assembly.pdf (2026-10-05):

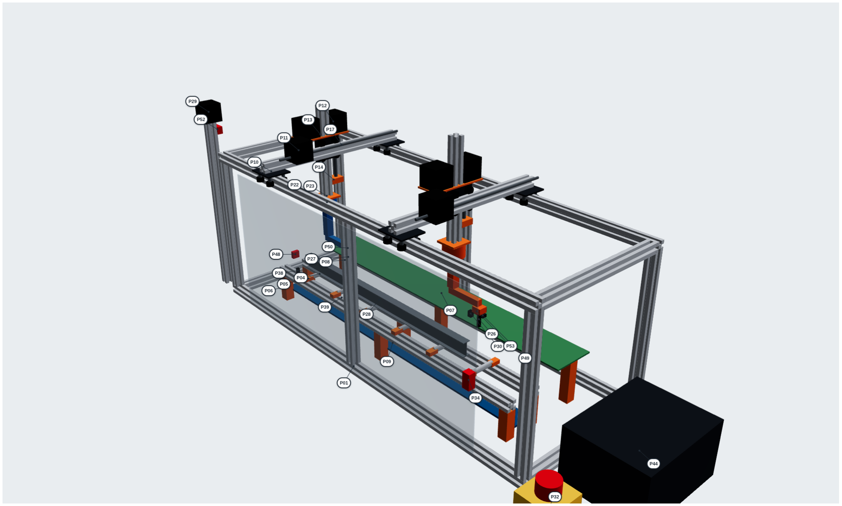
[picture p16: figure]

Steel Beam Cutting Cell - 1:10 prototype Sheet: general assembly | Drawing: BC-P1-GA
Drawn: Ravi Mahadeva Date: 05 Oct 2026 Units: mm Scale: not to scale | Sheet 1 CAD: cad/prototype_1to10.step

# General assembly

Each balloon is a part number (P01 ...) - the same number as the shopping list and the CAD. The table lists every part in the model and how many there are.
Part | Name | No.
P01 | V-slot 20x20 aluminium extrusion | 21
P04 | Bed rollers | 6
P05 | Roller brackets (3D printed) | 12
P06 | Bed riser blocks (3D printed) | 6
P07 | Outfeed table board | 1
P08 | Outfeed table risers (3D printed) | 3
P09 | Scrap tray (3D printed) | 1
P10 | Mini V-wheel gantry plate kits | 46
P11 | NEMA 17 stepper motor | 4
P12 | NEMA 17 with integrated T8 lead screw | 4
P13 | Z motor bracket (3D printed) | 2
P14 | Lead-screw nut block (3D printed) | 2
P17 | 5 mm cross shafts + bearings | 2
P22 | MeArm-type 4-servo arm kit | 8
P23 | Arm mount plate (3D printed) | 2
P26 | Cutter 'torch' for the prototype (pen holder) | 1
P27 | Handler magnet | 1
P28 | Model beams (3D printed) | 1
P29 | USB wide-angle camera (safety zone) | 1
P30 | CSI camera (close-up of the Cutter) | 1
P32 | Emergency stop station | 2
P34 | Door interlock switch | 1
P38 | IR break-beam sensor pair | 2
P39 | Polycarbonate sheet 2 mm | 1
P44 | Control box | 1
P48 | VL53L1X time-of-flight distance sensor | 1
P49 | Pen touch-off micro-switch | 1
P50 | Load cell 1 kg + HX711 | 1
P52 | IR flame sensor module | 1
P53 | Line laser module (Class 2) | 1

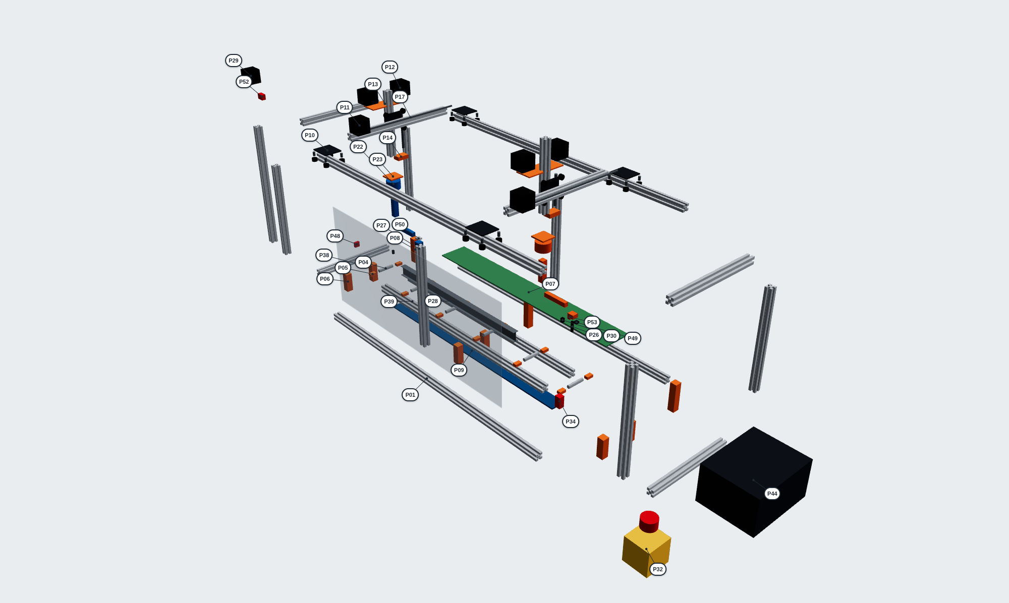
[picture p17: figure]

## Steel Beam Cutting Cell - 1:10 prototype

Sheet: exploded view

Drawing: BC-P1-GA

# Exploded view - what goes where

The parts pulled apart from the middle so you can see how they fit together.
Part | Name | No.
P01 | V-slot 20x20 aluminium extrusion | 21
P04 | Bed rollers | 6
P05 | Roller brackets (3D printed) | 12
P06 | Bed riser blocks (3D printed) | 6
P07 | Outfeed table board | 1
P08 | Outfeed table risers (3D printed) | 3
P09 | Scrap tray (3D printed) | 1
P10 | Mini V-wheel gantry plate kits | 46
P11 | NEMA 17 stepper motor | 4
P12 | NEMA 17 with integrated T8 lead screw | 4
P13 | Z motor bracket (3D printed) | 2
P14 | Lead-screw nut block (3D printed) | 2
P17 | 5 mm cross shafts + bearings | 2
P22 | MeArm-type 4-servo arm kit | 8
P23 | Arm mount plate (3D printed) | 2
P26 | Cutter 'torch' for the prototype (pen holder) | 1
P27 | Handler magnet | 1
P28 | Model beams (3D printed) | 1
P29 | USB wide-angle camera (safety zone) | 1
P30 | CSI camera (close-up of the Cutter) | 1
P32 | Emergency stop station | 2
P34 | Door interlock switch | 1
P38 | IR break-beam sensor pair | 2
P39 | Polycarbonate sheet 2 mm | 1
P44 | Control box | 1
P48 | VL53L1X time-of-flight distance sensor | 1
P49 | Pen touch-off micro-switch | 1
P50 | Load cell 1 kg + HX711 | 1
P52 | IR flame sensor module | 1
P53 | Line laser module (Class 2) | 1

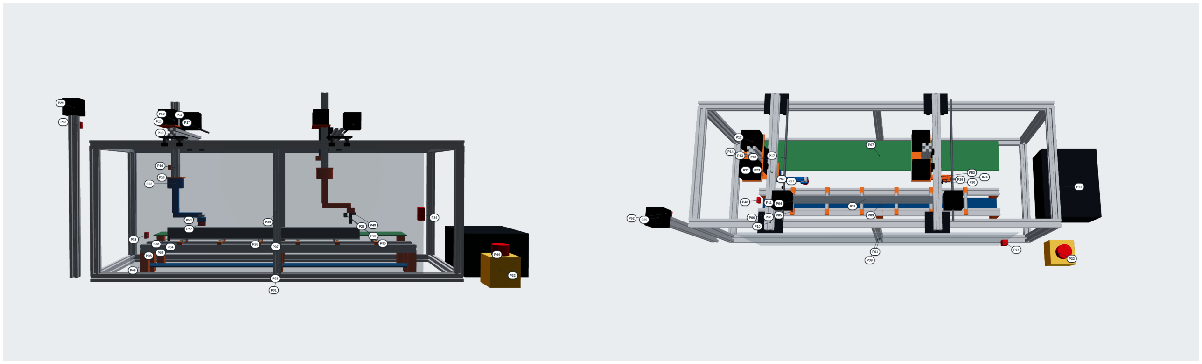
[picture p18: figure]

## Steel Beam Cutting Cell - 1:10 prototype

Sheet: front and top views

Drawing: BC-P1-GA

# Front view and top view

Front - from the operator's side | Top - looking down

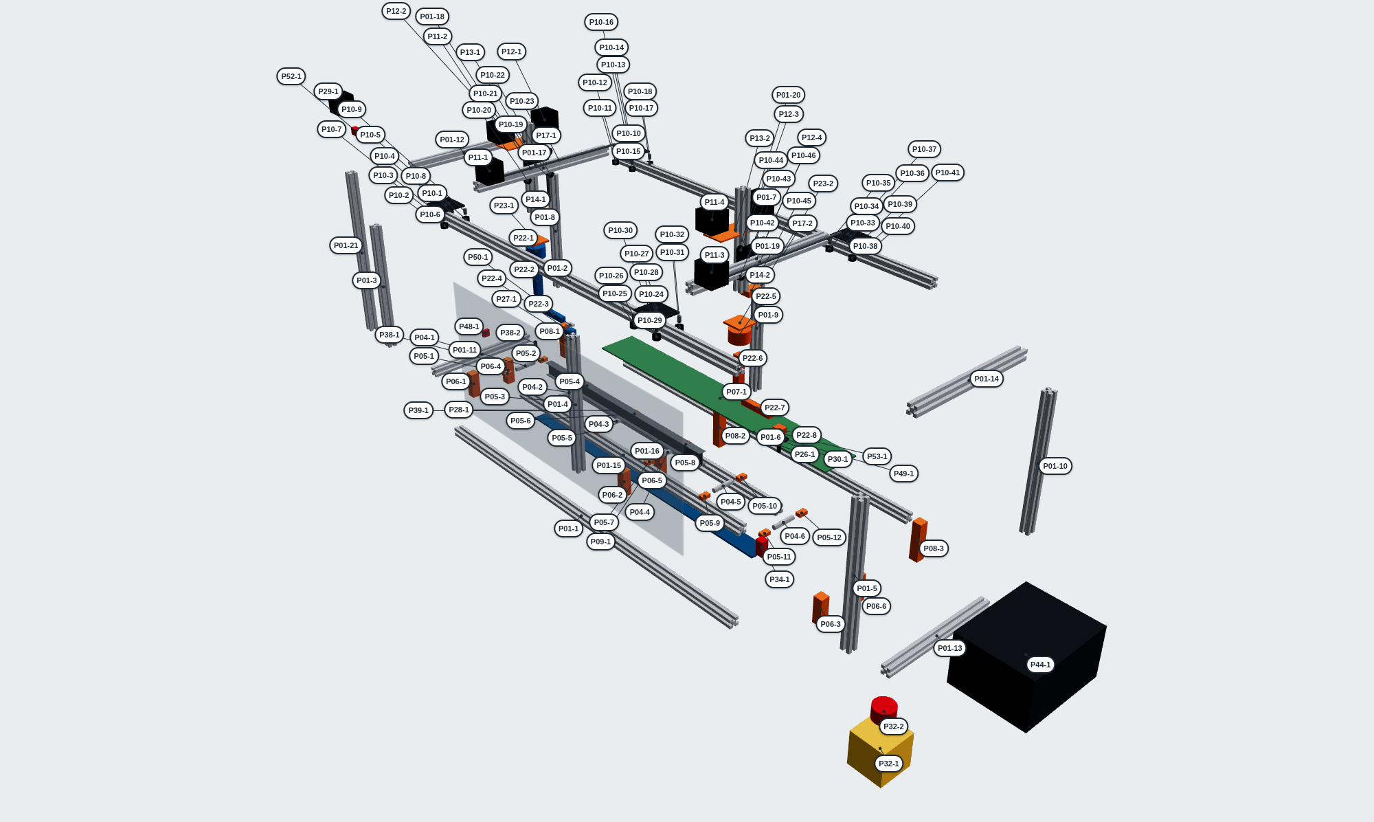
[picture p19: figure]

## Steel Beam Cutting Cell - 1:10 prototype

Sheet: every position

Drawing: BC-P1-GA

# Every position

Each balloon is a position: part number - copy (P11-2 = the second NEMA 17 motor). The list on the following sheets says what each position is and where it goes.

## Steel Beam Cutting Cell - 1:10 prototype

Sheet: parts list

Drawing: BC-P1-GA

# Parts list - part numbers, positions and where to buy

Part | Name | What to look for | Positions in the model | Buy | Each | Where to buy
P01 | V-slot 20x20 aluminium extrusion | cut to size - lengths in cad/prototype_cut_list.csv (frame, bed rails, bridges, Z axes, camera post) | P01-1, P01-2, P01-3, P01-4, P01-5, P01-6, P01-7, P01-8, P01-9, P01-10, P01-11, P01-12, P01-13, P01-14, P01-15, P01-16, P01-17, P01-18, P01-19, P01-20, P01-21 | 9.5 m | £8 | Ooznest (cut to size), Amazon UK search shop (https://ooznest.co.uk/?s=20x20mm+V-Slot+cut+to+size&post_type=product)
P02 | Corner brackets + M5 T-nuts + M5 bolts | 30 cast 20-series corner brackets, 120 drop-in T-nuts, M5x8 button heads | not drawn (wiring, inside the control box, tools) | 1 kit | £30 | Ooznest, Amazon UK search shop (https://ooznest.co.uk/?s=cast+corner+bracket+20+series&post_type=product)
P03 | Rubber feet | stick-on rubber feet 20 mm | not drawn (wiring, inside the control box, tools) | 4 | £1 | Amazon UK search shop (https://www.amazon.co.uk/s?k=rubber+feet+20mm+self+adhesive)
P04 | Bed rollers | 10 mm printed sleeves on 3 mm silver steel rod (50 mm), 2 x 623ZZ bearings each | P04-1, P04-2, P04-3, P04-4, P04-5, P04-6 | 6 | £2 | Amazon UK, Simply Bearings search shop (https://www.amazon.co.uk/s?k=623ZZ+bearings+3mm)
P05 | Roller brackets (3D printed) | PETG, clip on the 20x20 bed rails | P05-1, P05-2, P05-3, P05-4, P05-5, P05-6, P05-7, P05-8, P05-9, P05-10, P05-11, P05-12 | 12 | £0 | print make / print it
P06 | Bed riser blocks (3D printed) | PETG blocks that hold the bed rails 60 mm above the base | P06-1, P06-2, P06-3, P06-4, P06-5, P06-6 | 6 | £0 | print make / print it
P07 | Outfeed table board | 3 mm plywood strip 700 x 90 mm | P07-1 | 1 | £4 | builders' merchant, Amazon UK search shop (https://www.amazon.co.uk/s?k=3mm+plywood+sheet)
P08 | Outfeed table risers (3D printed) | PETG | P08-1, P08-2, P08-3 | 3 | £0 | print make / print it
P09 | Scrap tray (3D printed) | 700 x 44 mm tray under the bed | P09-1 | 1 | £0 | print make / print it
P10 | Mini V-wheel gantry plate kits | 20-series mini gantry plate + 4 mini V-wheels (625 bearings) + eccentric spacers | P10-1, P10-2, P10-3, P10-4, P10-5, P10-6, P10-7, P10-8, P10-9, P10-10, P10-11, P10-12, P10-13, P10-14, P10-15, P10-16, P10-17, P10-18, P10-19, P10-20, P10-21, P10-22, P10-23, P10-24, P10-25, P10-26, P10-27, P10-28, P10-29, P10-30, P10-31, P10-32, P10-33, P10-34, P10-35, P10-36, P10-37, P10-38, P10-39, P10-40, P10-41, P10-42, P10-43, P10-44, P10-45, P10-46 | 6 | £12 | Ooznest search shop (https://ooznest.co.uk/?s=mini+V-wheel+gantry+plate&post_type=product)
P11 | NEMA 17 stepper motor | 1.5-2 A, 40 mm body, 5 mm shaft (a NEMA 14 is lighter if you prefer) | P11-1, P11-2, P11-3, P11-4 | 4 | £12 | Ooznest, StepperOnline search shop (https://www.omc-stepperonline.com/search?search=nema+17+stepper+motor+40mm)
P12 | NEMA 17 with integrated T8 lead screw | T8 x 2 mm lead, 150 mm screw, with brass nut | P12-1, P12-2, P12-3, P12-4 | 2 | £22 | StepperOnline, Amazon UK search shop (https://www.omc-stepperonline.com/search?search=nema+17+lead+screw+T8+150mm)
P13 | Z motor bracket (3D printed) | PETG shelf on top of the carriage plate, holds the Z and Y motors | P13-1, P13-2 | 2 | £0 | print make / print it
P14 | Lead-screw nut block (3D printed) | PETG block with the brass T8 nut, fixed to the Z axis | P14-1, P14-2 | 2 | £0 | print make / print it
P15 | GT2 belt 6 mm | 5 m (2 per bridge along the rails, 1 per carriage) | not drawn (wiring, inside the control box, tools) | 1 | £8 | Ooznest search shop (https://ooznest.co.uk/?s=GT2+belt+6mm&post_type=product)
P16 | GT2 16T pulleys + idlers | 4 x 16T 5 mm bore (cross shafts), 2 x 16T (Y), 8 idlers | not drawn (wiring, inside the control box, tools) | 1 set | £20 | Ooznest, Amazon UK search shop (https://ooznest.co.uk/?s=GT2+pulley+16+tooth&post_type=product)
P17 | 5 mm cross shafts + bearings | 2 x 360 mm 5 mm silver steel, 4 x 625ZZ in printed blocks, 2 x 5-5 mm couplers | P17-1, P17-2 | 1 set | £12 | Amazon UK, Simply Bearings search shop (https://www.amazon.co.uk/s?k=5mm+linear+shaft+400mm)
P18 | Home / limit switches | mechanical microswitch with lever, NC wiring | not drawn (wiring, inside the control box, tools) | 8 | £1.50 | Amazon UK search shop (https://www.amazon.co.uk/s?k=micro+limit+switch+lever+pack)
P19 | FluidNC 6-axis CNC controller (ESP32) | 6 driver sockets, USB to the Jetson (e.g. Elecrow / Bart Dring 6x CNC Controller) | not drawn (wiring, inside the control box, tools) | 1 | £40 | Elecrow, Tindie product page (https://www.elecrow.com/6x-cnc-controller-for-fluidnc.html)
P20 | TMC2209 stepper driver modules | StepStick format | not drawn (wiring, inside the control box, tools) | 6 | £5 | Amazon UK, Ooznest search shop (https://www.amazon.co.uk/s?k=TMC2209+stepper+driver+stepstick)
P21 | Motor cable + drag chain | 5 m 4-core 0.25 mm2, 1 m 7x7 drag chain | not drawn (wiring, inside the control box, tools) | 1 set | £15 | Amazon UK search shop (https://www.amazon.co.uk/s?k=4+core+cable+0.25mm+drag+chain+7x7)
P22 | MeArm-type 4-servo arm kit | small 4-servo arm with MG90S metal-gear micro servos (reach ~150 mm); swap the gripper for the pen / magnet | P22-1, P22-2, P22-3, P22-4, P22-5, P22-6, P22-7, P22-8 | 2 | £37 | Cool Components, Kitronik product page (https://coolcomponents.co.uk/collections/kits/robotic-arm)
P23 | Arm mount plate (3D printed) | PETG plate: bolts the arm base under the Z axis | P23-1, P23-2 | 2 | £0 | print make / print it
P24 | PCA9685 16-channel servo board | I2C - wired straight to the Jetson's 40-pin header (pins 3 / 5), drives all 8 servos | not drawn (wiring, inside the control box, tools) | 1 | £6 | Amazon UK, kunkune product page (https://kunkune.co.uk/?p=11021)
P25 | 5 V power supply for the servos | Mean Well LRS-35-5 (5 V 7 A) - servos and magnet | not drawn (wiring, inside the control box, tools) | 1 | £12 | RS, Farnell search shop (https://uk.rs-online.com/web/c/?searchTerm=Mean+Well+LRS-35-5)

## Steel Beam Cutting Cell - 1:10 prototype

Sheet: position list

Drawing: BC-P1-GA

Part | Name | What to look for | Positions in the model | Buy | Each | Where to buy
P26 | Cutter 'torch' for the prototype (pen holder) | fine-liner pen in a sprung 3D-printed holder (marks every cut line on the model beam) | P26-1 | 1 | £2 | print make / print it
P27 | Handler magnet | 5 V 20 mm lifting electromagnet (~2.5 kg hold) + MOSFET module + flyback diode | P27-1 | 1 | £8 | Amazon UK search shop (https://www.amazon.co.uk/s?k=5V+electromagnet+20mm+lifting)
P28 | Model beams (3D printed) | UB 305x165 at 1:10 (30 x 16 mm), 500 mm long, with steel tape on the top flange | P28-1 | 4 | £0 | print make / print it
P29 | USB wide-angle camera (safety zone) | 1080p UVC, 90-120 deg view (e.g. Logitech C920/C922 or an Arducam USB wide-angle) | P29-1 | 1 | £50 | Amazon UK, Pimoroni search shop (https://www.amazon.co.uk/s?k=Logitech+C920+webcam)
P30 | CSI camera (close-up of the Cutter) | Arducam IMX219 for Jetson Orin Nano (22-pin cable), wide-angle lens | P30-1 | 1 | £25 | Arducam, RobotShop UK product page (https://www.arducam.com/arducam-imx219-pdaf-cdaf-autofocus-camera-module-with-case-for-raspberry-pi-nvidiar-jetson-orin-series.html)
P31 | Powered USB 3 hub | 4-port, own power supply | not drawn (wiring, inside the control box, tools) | 1 | £20 | Amazon UK search shop (https://www.amazon.co.uk/s?k=powered+USB+3.0+hub+4+port)
P32 | Emergency stop station | yellow box, red 40 mm mushroom, turn to release, 2 NC contacts (e.g. Schneider Harmony XALK178 family) | P32-1, P32-2 | 1 | £42 | RS, Farnell, TME search shop (https://uk.rs-online.com/web/c/?searchTerm=XALK178)
P33 | Safety relay | Pilz PNOZ s3 24 V DC (dual channel, manual reset) or equivalent | not drawn (wiring, inside the control box, tools) | 1 | £180 | RS, Farnell (new) / ~£75 used search shop (https://uk.farnell.com/search?st=PNOZ+s3+751103)
P34 | Door interlock switch | non-contact coded magnetic safety switch, NC (e.g. Pilz PSEN or Schmersal BNS) | P34-1 | 1 | £60 | RS, Farnell search shop (https://uk.rs-online.com/web/c/?searchTerm=non+contact+safety+switch+coded)
P35 | Reset push button | 22 mm blue illuminated, 1 NO | not drawn (wiring, inside the control box, tools) | 1 | £8 | RS, Amazon UK search shop (https://uk.rs-online.com/web/c/?searchTerm=22mm+blue+illuminated+push+button)
P36 | Stack light | 24 V mini LED tower, red / amber / green | not drawn (wiring, inside the control box, tools) | 1 | £15 | Amazon UK search shop (https://www.amazon.co.uk/s?k=24V+mini+LED+stack+light+3+colour)
P37 | 4-channel relay module (opto-isolated) | 3.3 V logic input, 24 V contacts | not drawn (wiring, inside the control box, tools) | 1 | £8 | Amazon UK search shop (https://www.amazon.co.uk/s?k=4+channel+relay+module+optocoupler+3.3V)
P38 | IR break-beam sensor pair | 5 mm IR break-beam (demonstrates the light-curtain input) | P38-1, P38-2 | 2 | £6 | Pimoroni, The Pi Hut search shop (https://thepihut.com/search?q=IR+break+beam+sensor)
P39 | Polycarbonate sheet 2 mm | front door, ends and lid (~0.6 m2) - polycarbonate, not acrylic (acrylic shatters) | P39-1 | 0.6 m2 | £35 | plastics stockist, Amazon UK search shop (https://www.amazon.co.uk/s?k=2mm+polycarbonate+sheet+clear)
P40 | Hinges + handle | 2 small hinges, 1 handle (20-series) | not drawn (wiring, inside the control box, tools) | 1 set | £12 | Ooznest, Amazon UK search shop (https://ooznest.co.uk/?s=hinge+20+series&post_type=product)
P41 | 24 V power supply | Mean Well LRS-100-24 (24 V 4.5 A) - motors, controller, safety circuit | not drawn (wiring, inside the control box, tools) | 1 | £14 | RS, Farnell search shop (https://uk.rs-online.com/web/c/?searchTerm=Mean+Well+LRS-100-24)
P42 | IEC mains inlet with switch and fuse | panel mount, 3 A fuse | not drawn (wiring, inside the control box, tools) | 1 | £8 | RS, Farnell search shop (https://uk.rs-online.com/web/c/?searchTerm=IEC+inlet+switch+fuse)
P43 | DIN rail + terminals + fuse holders | short 35 mm DIN rail, 12 terminals, 3 x 5x20 fuse holders | not drawn (wiring, inside the control box, tools) | 1 set | £20 | RS, Farnell search shop (https://uk.rs-online.com/web/c/?searchTerm=DIN+rail+terminal+block+fuse+holder)
P44 | Control box | ABS enclosure ~200 x 160 x 110 with cable glands | P44-1 | 1 | £20 | RS, CPC search shop (https://uk.rs-online.com/web/c/?searchTerm=ABS+enclosure+200x160)
P45 | Wire + ferrules + crimp tool | 0.5 and 0.75 mm2 flexible, ferrule kit | not drawn (wiring, inside the control box, tools) | 1 set | £25 | Amazon UK, CPC search shop (https://www.amazon.co.uk/s?k=ferrule+crimp+tool+kit)
P46 | Jetson Orin Nano Super (4 GB) | you already have it - docs/JETSON_SPECS.md | not drawn (wiring, inside the control box, tools) | 1 | £0 | - make / print it
P47 | PETG and PLA filament | 1 kg each | not drawn (wiring, inside the control box, tools) | 2 | £20 | Amazon UK, 3DJake search shop (https://www.amazon.co.uk/s?k=PETG+filament+1kg+1.75mm)
P48 | VL53L1X time-of-flight distance sensor | I2C breakout, up to 4 m - the datum sensor: finds where the model beam starts | P48-1 | 1 | £12 | Pimoroni, The Pi Hut search shop (https://shop.pimoroni.com/search?q=VL53L1X)
P49 | Pen touch-off micro-switch | micro-switch with roller lever, on the sprung pen holder - finds the beam surface (the prototype's initial height sensing) | P49-1 | 2 | £1.50 | Amazon UK, CPC search shop (https://www.amazon.co.uk/s?k=micro+switch+roller+lever)
P50 | Load cell 1 kg + HX711 | bar load cell 1 kg with HX711 amplifier - between the Handler's wrist and magnet: weighs the part (slipping, wrong part, not cut free) | P50-1 | 1 | £7 | Amazon UK, The Pi Hut search shop (https://www.amazon.co.uk/s?k=load+cell+1kg+HX711)
P51 | INA219 current sensor | I2C current sensor in the magnet supply - checks the magnet is really on | not drawn (wiring, inside the control box, tools) | 1 | £5 | Pimoroni, Amazon UK search shop (https://www.amazon.co.uk/s?k=INA219+current+sensor)
P52 | IR flame sensor module | IR flame sensor with digital output - demonstrates the fire detector | P52-1 | 1 | £3 | Amazon UK search shop (https://www.amazon.co.uk/s?k=IR+flame+sensor+module)

## Steel Beam Cutting Cell - 1:10 prototype

Drawing: BC-P1-GA

Part | Name | What to look for | Positions in the model | Buy | Each | Where to buy
P53 | Line laser module (Class 2) | 650 nm line laser, Class 1 or 2 (1 mW or less) - with camera 2 it shows the beam's real profile | P53-1 | 1 | £6 | Amazon UK search shop (https://www.amazon.co.uk/s?k=line+laser+module+650nm+1mW)

## Steel Beam Cutting Cell - 1:10 prototype

Drawing: BC-P1-GA

# Position list - what each position is and where it goes

x is along the machine (infeed end = 0), y across (front, the operator's side, is negative), z up from the table. Sizes in mm, centre of each part.
Position | Part | What it is | Where | x | y | z
P01-1 | V-slot 20x20 aluminium extrusion | 20x20 V-slot aluminium extrusion - base rail 900 mm | front (operator side), middle, 10 mm up | 300 | -150 | 10
P01-2 | V-slot 20x20 aluminium extrusion | 20x20 V-slot aluminium extrusion - gantry rail 900 mm (the bridges' wheels run on it) | front (operator side), middle, 330 mm up | 300 | -150 | 330
P01-3 | V-slot 20x20 aluminium extrusion | 20x20 V-slot aluminium extrusion - upright 300 mm | front (operator side), infeed end, 170 mm up | -140 | -150 | 170
P01-4 | V-slot 20x20 aluminium extrusion | 20x20 V-slot aluminium extrusion - upright 300 mm | front (operator side), middle, 170 mm up | 300 | -150 | 170
P01-5 | V-slot 20x20 aluminium extrusion | 20x20 V-slot aluminium extrusion - upright 300 mm | front (operator side), middle, 170 mm up | 740 | -150 | 170
P01-6 | V-slot 20x20 aluminium extrusion | 20x20 V-slot aluminium extrusion - base rail 900 mm | back, middle, 10 mm up | 300 | 150 | 10
P01-7 | V-slot 20x20 aluminium extrusion | 20x20 V-slot aluminium extrusion - gantry rail 900 mm (the bridges' wheels run on it) | back, middle, 330 mm up | 300 | 150 | 330
P01-8 | V-slot 20x20 aluminium extrusion | 20x20 V-slot aluminium extrusion - upright 300 mm | back, infeed end, 170 mm up | -140 | 150 | 170
P01-9 | V-slot 20x20 aluminium extrusion | 20x20 V-slot aluminium extrusion - upright 300 mm | back, middle, 170 mm up | 300 | 150 | 170
P01-10 | V-slot 20x20 aluminium extrusion | 20x20 V-slot aluminium extrusion - upright 300 mm | back, middle, 170 mm up | 740 | 150 | 170
P01-11 | V-slot 20x20 aluminium extrusion | 20x20 V-slot aluminium extrusion - cross member 280 mm | middle, infeed end, 10 mm up | -140 | 0 | 10
P01-12 | V-slot 20x20 aluminium extrusion | 20x20 V-slot aluminium extrusion - cross member 280 mm | middle, infeed end, 330 mm up | -140 | 0 | 330
P01-13 | V-slot 20x20 aluminium extrusion | 20x20 V-slot aluminium extrusion - cross member 280 mm | middle, middle, 10 mm up | 740 | 0 | 10
P01-14 | V-slot 20x20 aluminium extrusion | 20x20 V-slot aluminium extrusion - cross member 280 mm | middle, middle, 330 mm up | 740 | 0 | 330
P01-15 | V-slot 20x20 aluminium extrusion | 20x20 V-slot aluminium extrusion - bed rail 700 mm | front (operator side), middle, 70 mm up | 300 | -80 | 70
P06-1 | Bed riser blocks (3D printed) | Bed riser block (3D printed) - holds the bed rails on the base | front (operator side), infeed end, 30 mm up | -40 | -80 | 30
P06-2 | Bed riser blocks (3D printed) | Bed riser block (3D printed) - holds the bed rails on the base | front (operator side), middle, 30 mm up | 300 | -80 | 30
P06-3 | Bed riser blocks (3D printed) | Bed riser block (3D printed) - holds the bed rails on the base | front (operator side), middle, 30 mm up | 640 | -80 | 30
P01-16 | V-slot 20x20 aluminium extrusion | 20x20 V-slot aluminium extrusion - bed rail 700 mm | middle, middle, 70 mm up | 300 | -20 | 70
P06-4 | Bed riser blocks (3D printed) | Bed riser block (3D printed) - holds the bed rails on the base | middle, infeed end, 30 mm up | -40 | -20 | 30
P06-5 | Bed riser blocks (3D printed) | Bed riser block (3D printed) - holds the bed rails on the base | middle, middle, 30 mm up | 300 | -20 | 30
P06-6 | Bed riser blocks (3D printed) | Bed riser block (3D printed) - holds the bed rails on the base | middle, middle, 30 mm up | 640 | -20 | 30
P04-1 | Bed rollers | Bed roller: 10 mm printed sleeve on a 3 mm steel rod, 2 x 623 bearings | middle, infeed end, 85 mm up | 50 | -50 | 85
P05-1 | Roller brackets (3D printed) | Roller bracket (3D printed, PETG) - clips on the bed rail | front (operator side), infeed end, 84 mm up | 50 | -80 | 84
P05-2 | Roller brackets (3D printed) | Roller bracket (3D printed, PETG) - clips on the bed rail | middle, infeed end, 84 mm up | 50 | -20 | 84
P04-2 | Bed rollers | Bed roller: 10 mm printed sleeve on a 3 mm steel rod, 2 x 623 bearings | middle, infeed end, 85 mm up | 150 | -50 | 85
P05-3 | Roller brackets (3D printed) | Roller bracket (3D printed, PETG) - clips on the bed rail | front (operator side), infeed end, 84 mm up | 150 | -80 | 84
P05-4 | Roller brackets (3D printed) | Roller bracket (3D printed, PETG) - clips on the bed rail | middle, infeed end, 84 mm up | 150 | -20 | 84
P04-3 | Bed rollers | Bed roller: 10 mm printed sleeve on a 3 mm steel rod, 2 x 623 bearings | middle, middle, 85 mm up | 250 | -50 | 85
P05-5 | Roller brackets (3D printed) | Roller bracket (3D printed, PETG) - clips on the bed rail | front (operator side), middle, 84 mm up | 250 | -80 | 84
P05-6 | Roller brackets (3D printed) | Roller bracket (3D printed, PETG) - clips on the bed rail | middle, middle, 84 mm up | 250 | -20 | 84
P04-4 | Bed rollers | Bed roller: 10 mm printed sleeve on a 3 mm steel rod, 2 x 623 bearings | middle, middle, 85 mm up | 350 | -50 | 85
P05-7 | Roller brackets (3D printed) | Roller bracket (3D printed, PETG) - clips on the bed rail | front (operator side), middle, 84 mm up | 350 | -80 | 84
P05-8 | Roller brackets (3D printed) | Roller bracket (3D printed, PETG) - clips on the bed rail | middle, middle, 84 mm up | 350 | -20 | 84
P04-5 | Bed rollers | Bed roller: 10 mm printed sleeve on a 3 mm steel rod, 2 x 623 bearings | middle, middle, 85 mm up | 450 | -50 | 85
P05-9 | Roller brackets (3D printed) | Roller bracket (3D printed, PETG) - clips on the bed rail | front (operator side), middle, 84 mm up | 450 | -80 | 84
P05-10 | Roller brackets (3D printed) | Roller bracket (3D printed, PETG) - clips on the bed rail | middle, middle, 84 mm up | 450 | -20 | 84
P04-6 | Bed rollers | Bed roller: 10 mm printed sleeve on a 3 mm steel rod, 2 x 623 bearings | middle, middle, 85 mm up | 550 | -50 | 85
P05-11 | Roller brackets (3D printed) | Roller bracket (3D printed, PETG) - clips on the bed rail | front (operator side), middle, 84 mm up | 550 | -80 | 84
P05-12 | Roller brackets (3D printed) | Roller bracket (3D printed, PETG) - clips on the bed rail | middle, middle, 84 mm up | 550 | -20 | 84
P09-1 | Scrap tray (3D printed) | Scrap tray (3D printed) - offcuts fall into it | middle, middle, 22 mm up | 300 | -50 | 22
P07-1 | Outfeed table board | Outfeed table: 3 mm plywood strip on printed risers | back, middle, 88 mm up | 300 | 85 | 88
P08-1 | Outfeed table risers (3D printed) | Outfeed table riser (3D printed) | back, infeed end, 44 mm up | -40 | 85 | 44
P08-2 | Outfeed table risers (3D printed) | Outfeed table riser (3D printed) | back, middle, 44 mm up | 300 | 85 | 44
P08-3 | Outfeed table risers (3D printed) | Outfeed table riser (3D printed) | back, middle, 44 mm up | 640 | 85 | 44
P28-1 | Model beams (3D printed) | Model beam: UB 305x165x40 at 1:10 (30 x 16 mm), 3D printed, steel tape on top | middle, middle, 105 mm up | 260 | -50 | 105

## Steel Beam Cutting Cell - 1:10 prototype

Drawing: BC-P1-GA

Position | Part | What it is | Where | x | y | z
P01-17 | V-slot 20x20 aluminium extrusion | Handler bridge: 20x20 V-slot aluminium extrusion 340 mm | middle, infeed end, 359 mm up | 50 | 0 | 359
P10-1 | Mini V-wheel gantry plate kits | Handler bridge end: mini V-wheel gantry plate (20 series), clamps the gantry rail | front (operator side), infeed end, 348 mm up | 50 | -150 | 348
P10-2 | Mini V-wheel gantry plate kits | Mini V-wheel (625 bearing) on an eccentric spacer - runs in the rail's side slot | front (operator side), infeed end, 330 mm up | 32 | -166 | 330
P10-3 | Mini V-wheel gantry plate kits | Eccentric spacer + M5 bolt: holds the V-wheel under the gantry plate | front (operator side), infeed end, 340 mm up | 32 | -166 | 340
P10-4 | Mini V-wheel gantry plate kits | Mini V-wheel (625 bearing) on an eccentric spacer - runs in the rail's side slot | front (operator side), infeed end, 330 mm up | 32 | -134 | 330
P10-5 | Mini V-wheel gantry plate kits | Eccentric spacer + M5 bolt: holds the V-wheel under the gantry plate | front (operator side), infeed end, 340 mm up | 32 | -134 | 340
P10-6 | Mini V-wheel gantry plate kits | Mini V-wheel (625 bearing) on an eccentric spacer - runs in the rail's side slot | front (operator side), infeed end, 330 mm up | 68 | -166 | 330
P10-7 | Mini V-wheel gantry plate kits | Eccentric spacer + M5 bolt: holds the V-wheel under the gantry plate | front (operator side), infeed end, 340 mm up | 68 | -166 | 340
P10-8 | Mini V-wheel gantry plate kits | Mini V-wheel (625 bearing) on an eccentric spacer - runs in the rail's side slot | front (operator side), infeed end, 330 mm up | 68 | -134 | 330
P10-9 | Mini V-wheel gantry plate kits | Eccentric spacer + M5 bolt: holds the V-wheel under the gantry plate | front (operator side), infeed end, 340 mm up | 68 | -134 | 340
P10-10 | Mini V-wheel gantry plate kits | Handler bridge end: mini V-wheel gantry plate (20 series), clamps the gantry rail | back, infeed end, 348 mm up | 50 | 150 | 348
P10-11 | Mini V-wheel gantry plate kits | Mini V-wheel (625 bearing) on an eccentric spacer - runs in the rail's side slot | back, infeed end, 330 mm up | 32 | 134 | 330
P10-12 | Mini V-wheel gantry plate kits | Eccentric spacer + M5 bolt: holds the V-wheel under the gantry plate | back, infeed end, 340 mm up | 32 | 134 | 340
P10-13 | Mini V-wheel gantry plate kits | Mini V-wheel (625 bearing) on an eccentric spacer - runs in the rail's side slot | back, infeed end, 330 mm up | 32 | 166 | 330
P10-14 | Mini V-wheel gantry plate kits | Eccentric spacer + M5 bolt: holds the V-wheel under the gantry plate | back, infeed end, 340 mm up | 32 | 166 | 340
P10-15 | Mini V-wheel gantry plate kits | Mini V-wheel (625 bearing) on an eccentric spacer - runs in the rail's side slot | back, infeed end, 330 mm up | 68 | 134 | 330
P10-16 | Mini V-wheel gantry plate kits | Eccentric spacer + M5 bolt: holds the V-wheel under the gantry plate | back, infeed end, 340 mm up | 68 | 134 | 340
P10-17 | Mini V-wheel gantry plate kits | Mini V-wheel (625 bearing) on an eccentric spacer - runs in the rail's side slot | back, infeed end, 330 mm up | 68 | 166 | 330
P10-18 | Mini V-wheel gantry plate kits | Eccentric spacer + M5 bolt: holds the V-wheel under the gantry plate | back, infeed end, 340 mm up | 68 | 166 | 340
P11-1 | NEMA 17 stepper motor | Handler X motor: NEMA 17 driving both rails through a 5 mm cross shaft and GT2 belts | front (operator side), infeed end, 390 mm up | 85 | -105 | 390
P17-1 | 5 mm cross shafts + bearings | 5 mm cross shaft with GT2 16T pulleys at both ends | middle, infeed end, 379 mm up | 85 | 0 | 379
P10-19 | Mini V-wheel gantry plate kits | Handler carriage: mini V-wheel gantry plate on the side of the bridge (Y axis) | middle, infeed end, 359 mm up | 32 | 0 | 359
P10-20 | Mini V-wheel gantry plate kits | Mini V-wheel (625 bearing) - runs in the bridge's top / bottom slot | middle, infeed end, 343 mm up | 38 | -18 | 343
P10-21 | Mini V-wheel gantry plate kits | Mini V-wheel (625 bearing) - runs in the bridge's top / bottom slot | middle, infeed end, 375 mm up | 38 | -18 | 375
P10-22 | Mini V-wheel gantry plate kits | Mini V-wheel (625 bearing) - runs in the bridge's top / bottom slot | middle, infeed end, 343 mm up | 38 | 18 | 343
P10-23 | Mini V-wheel gantry plate kits | Mini V-wheel (625 bearing) - runs in the bridge's top / bottom slot | middle, infeed end, 375 mm up | 38 | 18 | 375
P13-1 | Z motor bracket (3D printed) | Handler motor shelf (3D printed): holds the Z and Y motors on top of the carriage plate | middle, infeed end, 384 mm up | 10 | 0 | 384
P11-2 | NEMA 17 stepper motor | Handler Y motor: NEMA 17 + GT2 belt along the bridge | middle, infeed end, 406 mm up | 10 | -35 | 406
P12-1 | NEMA 17 with integrated T8 lead screw | Handler Z motor: NEMA 17 with integrated T8 x 2 mm lead screw (150 mm) | middle, infeed end, 406 mm up | 10 | 35 | 406
P01-18 | V-slot 20x20 aluminium extrusion | Handler Z axis: 20x20 V-slot aluminium extrusion 200 mm on a T8 lead screw (slides on the carriage plate) | middle, infeed end, 350 mm up | 21 | 0 | 350
P12-2 | NEMA 17 with integrated T8 lead screw | T8 x 2 mm lead screw, 150 mm | middle, infeed end, 327 mm up | 10 | 35 | 327
P14-1 | Lead-screw nut block (3D printed) | Handler lead-screw nut block on the Z axis (3D printed + brass T8 nut) | middle, infeed end, 276 mm up | 10 | 28 | 276
P23-1 | Arm mount plate (3D printed) | Handler arm mount plate (3D printed) | middle, infeed end, 248 mm up | 21 | 0 | 248
P22-1 | MeArm-type 4-servo arm kit | Handler arm: MeArm-type 4-servo arm kit (MG90S servos) - base | middle, infeed end, 233 mm up | 21 | 0 | 233
P22-2 | MeArm-type 4-servo arm kit | Handler arm: upper arm (~80 mm) | middle, infeed end, 188 mm up | 21 | 0 | 188
P22-3 | MeArm-type 4-servo arm kit | Handler arm: forearm (~80 mm) | middle, infeed end, 149 mm up | 53 | 0 | 149
P22-4 | MeArm-type 4-servo arm kit | Handler arm: wrist / tool holder | middle, infeed end, 136 mm up | 91 | 0 | 136
P27-1 | Handler magnet | Handler magnet: 5 V 20 mm lifting electromagnet (holds about 2.5 kg) | middle, infeed end, 125 mm up | 91 | 0 | 125
P01-19 | V-slot 20x20 aluminium extrusion | Cutter bridge: 20x20 V-slot aluminium extrusion 340 mm | middle, middle, 359 mm up | 450 | 0 | 359
P10-24 | Mini V-wheel gantry plate kits | Cutter bridge end: mini V-wheel gantry plate (20 series), clamps the gantry rail | front (operator side), middle, 348 mm up | 450 | -150 | 348
P10-25 | Mini V-wheel gantry plate kits | Mini V-wheel (625 bearing) on an eccentric spacer - runs in the rail's side slot | front (operator side), middle, 330 mm up | 432 | -166 | 330
P10-26 | Mini V-wheel gantry plate kits | Eccentric spacer + M5 bolt: holds the V-wheel under the gantry plate | front (operator side), middle, 340 mm up | 432 | -166 | 340
P10-27 | Mini V-wheel gantry plate kits | Mini V-wheel (625 bearing) on an eccentric spacer - runs in the rail's side slot | front (operator side), middle, 330 mm up | 432 | -134 | 330
P10-28 | Mini V-wheel gantry plate kits | Eccentric spacer + M5 bolt: holds the V-wheel under the gantry plate | front (operator side), middle, 340 mm up | 432 | -134 | 340
P10-29 | Mini V-wheel gantry plate kits | Mini V-wheel (625 bearing) on an eccentric spacer - runs in the rail's side slot | front (operator side), middle, 330 mm up | 468 | -166 | 330
P10-30 | Mini V-wheel gantry plate kits | Eccentric spacer + M5 bolt: holds the V-wheel under the gantry plate | front (operator side), middle, 340 mm up | 468 | -166 | 340
P10-31 | Mini V-wheel gantry plate kits | Mini V-wheel (625 bearing) on an eccentric spacer - runs in the rail's side slot | front (operator side), middle, 330 mm up | 468 | -134 | 330
P10-32 | Mini V-wheel gantry plate kits | Eccentric spacer + M5 bolt: holds the V-wheel under the gantry plate | front (operator side), middle, 340 mm up | 468 | -134 | 340
P10-33 | Mini V-wheel gantry plate kits | Cutter bridge end: mini V-wheel gantry plate (20 series), clamps the gantry rail | back, middle, 348 mm up | 450 | 150 | 348

## Steel Beam Cutting Cell - 1:10 prototype

Drawing: BC-P1-GA

Position | Part | What it is | Where | x | y | z
P10-34 | Mini V-wheel gantry plate kits | Mini V-wheel (625 bearing) on an eccentric spacer - runs in the rail's side slot | back, middle, 330 mm up | 432 | 134 | 330
P10-35 | Mini V-wheel gantry plate kits | Eccentric spacer + M5 bolt: holds the V-wheel under the gantry plate | back, middle, 340 mm up | 432 | 134 | 340
P10-36 | Mini V-wheel gantry plate kits | Mini V-wheel (625 bearing) on an eccentric spacer - runs in the rail's side slot | back, middle, 330 mm up | 432 | 166 | 330
P10-37 | Mini V-wheel gantry plate kits | Eccentric spacer + M5 bolt: holds the V-wheel under the gantry plate | back, middle, 340 mm up | 432 | 166 | 340
P10-38 | Mini V-wheel gantry plate kits | Mini V-wheel (625 bearing) on an eccentric spacer - runs in the rail's side slot | back, middle, 330 mm up | 468 | 134 | 330
P10-39 | Mini V-wheel gantry plate kits | Eccentric spacer + M5 bolt: holds the V-wheel under the gantry plate | back, middle, 340 mm up | 468 | 134 | 340
P10-40 | Mini V-wheel gantry plate kits | Mini V-wheel (625 bearing) on an eccentric spacer - runs in the rail's side slot | back, middle, 330 mm up | 468 | 166 | 330
P10-41 | Mini V-wheel gantry plate kits | Eccentric spacer + M5 bolt: holds the V-wheel under the gantry plate | back, middle, 340 mm up | 468 | 166 | 340
P11-3 | NEMA 17 stepper motor | Cutter X motor: NEMA 17 driving both rails through a 5 mm cross shaft and GT2 belts | front (operator side), middle, 390 mm up | 485 | -105 | 390
P17-2 | 5 mm cross shafts + bearings | 5 mm cross shaft with GT2 16T pulleys at both ends | middle, middle, 379 mm up | 485 | 0 | 379
P10-42 | Mini V-wheel gantry plate kits | Cutter carriage: mini V-wheel gantry plate on the side of the bridge (Y axis) | middle, middle, 359 mm up | 432 | 0 | 359
P10-43 | Mini V-wheel gantry plate kits | Mini V-wheel (625 bearing) - runs in the bridge's top / bottom slot | middle, middle, 343 mm up | 438 | -18 | 343
P10-44 | Mini V-wheel gantry plate kits | Mini V-wheel (625 bearing) - runs in the bridge's top / bottom slot | middle, middle, 375 mm up | 438 | -18 | 375
P10-45 | Mini V-wheel gantry plate kits | Mini V-wheel (625 bearing) - runs in the bridge's top / bottom slot | middle, middle, 343 mm up | 438 | 18 | 343
P10-46 | Mini V-wheel gantry plate kits | Mini V-wheel (625 bearing) - runs in the bridge's top / bottom slot | middle, middle, 375 mm up | 438 | 18 | 375
P13-2 | Z motor bracket (3D printed) | Cutter motor shelf (3D printed): holds the Z and Y motors on top of the carriage plate | middle, middle, 384 mm up | 410 | 0 | 384
P11-4 | NEMA 17 stepper motor | Cutter Y motor: NEMA 17 + GT2 belt along the bridge | middle, middle, 406 mm up | 410 | -35 | 406
P12-3 | NEMA 17 with integrated T8 lead screw | Cutter Z motor: NEMA 17 with integrated T8 x 2 mm lead screw (150 mm) | middle, middle, 406 mm up | 410 | 35 | 406
P01-20 | V-slot 20x20 aluminium extrusion | Cutter Z axis: 20x20 V-slot aluminium extrusion 200 mm on a T8 lead screw (slides on the carriage plate) | middle, middle, 375 mm up | 421 | 0 | 375
P12-4 | NEMA 17 with integrated T8 lead screw | T8 x 2 mm lead screw, 150 mm | middle, middle, 339 mm up | 410 | 35 | 339
P14-2 | Lead-screw nut block (3D printed) | Cutter lead-screw nut block on the Z axis (3D printed + brass T8 nut) | middle, middle, 301 mm up | 410 | 28 | 301
P23-2 | Arm mount plate (3D printed) | Cutter arm mount plate (3D printed) | middle, middle, 273 mm up | 421 | 0 | 273
P22-5 | MeArm-type 4-servo arm kit | Cutter arm: MeArm-type 4-servo arm kit (MG90S servos) - base | middle, middle, 258 mm up | 421 | 0 | 258
P22-6 | MeArm-type 4-servo arm kit | Cutter arm: upper arm (~80 mm) | middle, middle, 213 mm up | 421 | 0 | 213
P22-7 | MeArm-type 4-servo arm kit | Cutter arm: forearm (~80 mm) | middle, middle, 174 mm up | 453 | 0 | 174
P22-8 | MeArm-type 4-servo arm kit | Cutter arm: wrist / tool holder | middle, middle, 161 mm up | 491 | 0 | 161
P26-1 | Cutter 'torch' for the prototype (pen holder) | Cutter 'torch' for the prototype: fine-liner pen in a sprung 3D-printed holder (marks the cut lines) | middle, middle, 140 mm up | 491 | 0 | 140
P44-1 | Control box | Control box: Jetson Orin Nano, FluidNC 6-axis board, PCA9685 servo board, 24 V and 5 V supplies, fuses, safety relay | middle, middle, 55 mm up | 850 | 0 | 55
P32-1 | Emergency stop station | Emergency stop: 40 mm red mushroom, 2 NC contacts, yellow box (BS EN ISO 13850) | front (operator side), middle, 35 mm up | 825 | -195 | 35
P32-2 | Emergency stop station | Emergency stop head | front (operator side), middle, 82 mm up | 825 | -195 | 82
P39-1 | Polycarbonate sheet 2 mm | Enclosure door: 2 mm polycarbonate on a 20x20 frame, with a safety interlock switch | front (operator side), middle, 170 mm up | 300 | -171 | 170
P34-1 | Door interlock switch | Door interlock switch (magnetic coded, NC) - opens = protective stop | front (operator side), middle, 165 mm up | 642 | -179 | 165
P29-1 | USB wide-angle camera (safety zone) | Camera: USB wide-angle (or IMX219 CSI) on a 20x20 post - YOLO watches the cell | front (operator side), infeed end, 420 mm up | -190 | -150 | 420
P01-21 | V-slot 20x20 aluminium extrusion | 20x20 V-slot aluminium extrusion - camera post | front (operator side), infeed end, 205 mm up | -190 | -150 | 205
P48-1 | VL53L1X time-of-flight distance sensor | Datum sensor: VL53L1X time-of-flight at the bed's infeed end - finds where the model beam starts | middle, infeed end, 100 mm up | -44 | -50 | 100
P38-1 | IR break-beam sensor pair | Bar-present IR break-beam (one each side of the bed) | front (operator side), infeed end, 96 mm up | 23 | -88 | 96
P38-2 | IR break-beam sensor pair | Bar-present IR break-beam (one each side of the bed) | middle, infeed end, 96 mm up | 23 | -12 | 96
P52-1 | IR flame sensor module | IR flame sensor module (demo of the fire detector) | front (operator side), infeed end, 378 mm up | -190 | -134 | 378
P50-1 | Load cell 1 kg + HX711 | Load cell (1 kg) between wrist and magnet - weighs the part: slipping, wrong part, not cut free | middle, infeed end, 147 mm up | 91 | 0 | 147
P30-1 | CSI camera (close-up of the Cutter) | Camera 2: IMX219 close-up beside the pen - the cut line, the bar edge | middle, middle, 149 mm up | 477 | -8 | 149
P53-1 | Line laser module (Class 2) | Line laser (Class 2) - with camera 2 it shows the beam's real profile | middle, middle, 148 mm up | 477 | 8 | 148
P49-1 | Pen touch-off micro-switch | Pen touch-off micro-switch on the sprung holder - finds the beam's surface | middle, middle, 152 mm up | 500 | 0 | 152

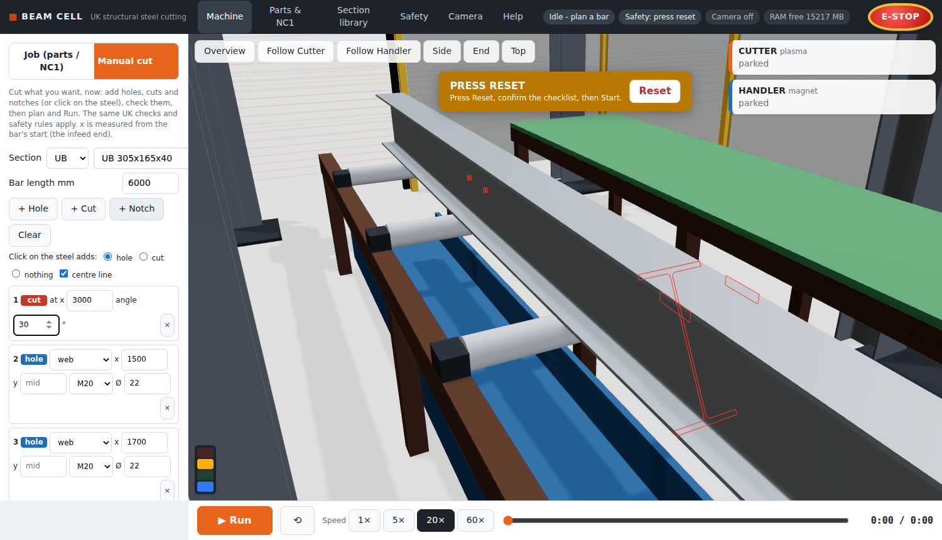
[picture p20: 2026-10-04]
docs/images/manual_cut.png

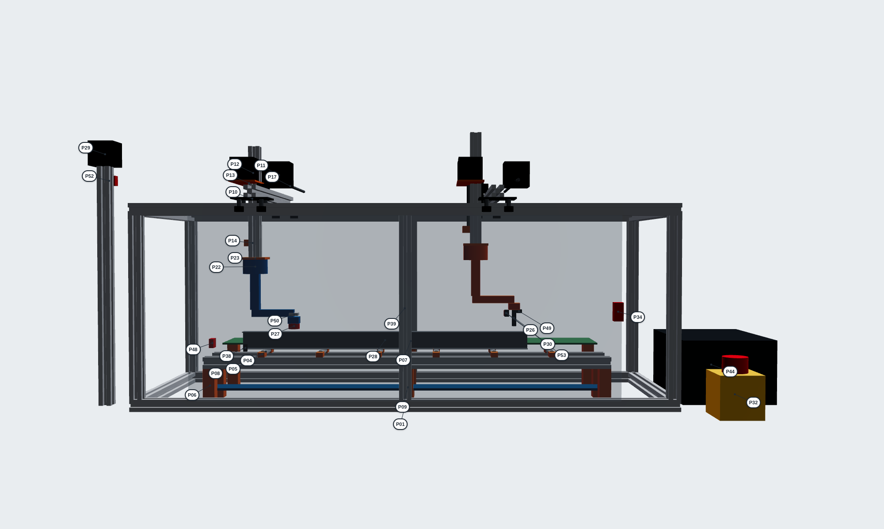
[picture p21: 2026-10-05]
docs/images/assembly_front.png

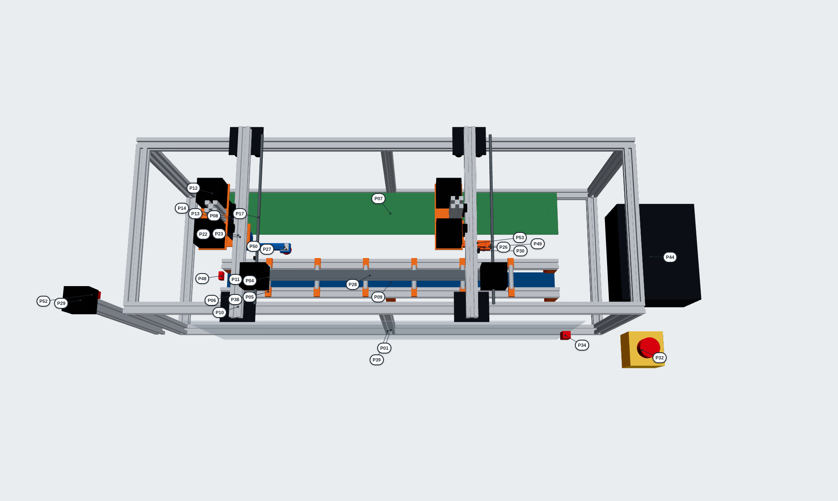
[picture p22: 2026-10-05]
docs/images/assembly_top.png

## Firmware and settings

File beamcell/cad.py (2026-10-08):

"""
Real CAD for the cell, the parts and the 1:10 prototype - solid models you can open in Fusion 360,
SolidWorks, FreeCAD, Onshape or Inventor (STEP), and the same model for the 3D view (GLB).

    python3 -m beamcell.cad                    everything below
    python3 -m beamcell.cad cell               cad/beam_cell.step  + web/models/*.glb (the 3D view)
    python3 -m beamcell.cad parts [files.nc1]  cad/parts/<mark>.step - one solid per NC1 part, with its
                                               holes, slots, notches and end cuts (default: examples/nc1)
    python3 -m beamcell.cad prototype          cad/prototype_1to10.step + cut list + positions + the Prototype tab's model

Needs CadQuery (pip install cadquery) - run it on a PC. The Jetson doesn't need it: the files
it makes are in the repo.

Units: STEP files in millimetres, GLB files in metres. Axes as everywhere in the project:
X along the bar (infeed -> outfeed end), Y across (+Y = the Cutter's side), Z up.

Every solid has a name and a label. The labels say what each thing is and, for the prototype,
what to buy or make - the 3D view shows them when you point at something.
"""
import csv
import glob
import math
import os
import sys

import numpy as np

from beamcell import machine as M
from beamcell import sections as S

try:
    import cadquery as cq
    from cadquery.occ_impl.exporters.assembly import exportGLTF
except ImportError:                                   # fine on the Jetson: the files are in the repo
    cq = None

ROOT = os.path.dirname(os.path.dirname(os.path.abspath(__file__)))
CAD_DIR = os.path.join(ROOT, "cad")
WEB_MODELS = os.path.join(ROOT, "web", "models")
RUNWAY_Z = M.RAIL_Z * 1000 - 550            # underside of the runway beams (UB 457x191x67, 453.4 deep)
CRANE_RAIL_TOP = RUNWAY_Z + 453.4 + 50      # top of the 50 mm crane rail on the runway: the wheels stand on it

# colours (0..1 RGB) - the same as the 3D view
STRUCTURE = (0.42, 0.45, 0.49)
YELLOW = (0.95, 0.76, 0.19)
DARK = (0.17, 0.19, 0.22)
STEEL = (0.44, 0.47, 0.50)
RUBBER = (0.10, 0.10, 0.10)
GREEN = (0.30, 0.55, 0.38)
BLUE_TRAY = (0.18, 0.37, 0.55)
BED = (0.33, 0.22, 0.16)
ALU = (0.75, 0.77, 0.80)
PRINTED = (0.92, 0.45, 0.12)
RED = (0.85, 0.12, 0.09)


def need_cadquery():
    if cq is None:
        raise SystemExit("CAD export needs CadQuery: pip install cadquery  (on a PC - the Jetson doesn't need it,\n"
                         "the STEP and GLB files are already in cad/ and web/models/)")


# ======================================================================= sections with true arcs
def _outline_path(s):
    """The cross-section as straight lines and true arcs: [("L", (u, v)) | ("A", cx, cy, r, a0, a1)]
    (mm, same shape and direction as sections.outline())."""
    k, h, b = s["kind"], s["h"], s["b"]
    if k == "I":
        tw, tf, r = s["tw"], s["tf"], s["r"]
        w = tw / 2
        return [("L", (-b / 2, 0)), ("L", (b / 2, 0)), ("L", (b / 2, tf)),
                ("A", w + r, tf + r, r, -90, -180), ("A", w + r, h - tf - r, r, 180, 90),
                ("L", (b / 2, h - tf)), ("L", (b / 2, h)), ("L", (-b / 2, h)), ("L", (-b / 2, h - tf)),
                ("A", -w - r, h - tf - r, r, 90, 0), ("A", -w - r, tf + r, r, 0, -90), ("L", (-b / 2, tf))]
    if k == "U":
        tw, tf, r = s["tw"], s["tf"], s["r"]
        x = b / 2 - tw
        return [("L", (-b / 2, 0)), ("L", (b / 2, 0)), ("L", (b / 2, h)), ("L", (-b / 2, h)), ("L", (-b / 2, h - tf)),
                ("A", x - r, h - tf - r, r, 90, 0), ("A", x - r, tf + r, r, 0, -90), ("L", (-b / 2, tf))]
    if k == "L":
        t, r1, r2 = s["t"], s["r1"], s["r2"]
        x = b / 2 - t
        return [("L", (-b / 2, 0)), ("L", (b / 2, 0)), ("L", (b / 2, h)),
                ("A", x + r2, h - r2, r2, 90, 180), ("A", x - r1, t + r1, r1, 0, -90),
                ("A", -b / 2 + r2, t - r2, r2, 90, 180)]
    raise ValueError(k)


def _wire(wp, path):
    """Draw a closed path on a workplane: lines and true arcs."""
    def at(cx, cy, r, a):
        return (cx + r * math.cos(math.radians(a)), cy + r * math.sin(math.radians(a)))

    first = path[0][1] if path[0][0] == "L" else at(*path[0][1:4], path[0][4])
    wp = wp.moveTo(*first)
    cur = first
    for seg in path[1:] if path[0][0] == "L" else path:
        if seg[0] == "L":
            if math.dist(cur, seg[1]) > 1e-6:
                wp = wp.lineTo(*seg[1])
            cur = seg[1]
        else:
            cx, cy, r, a0, a1 = seg[1:]
            p0, pm, p1 = at(cx, cy, r, a0), at(cx, cy, r, (a0 + a1) / 2), at(cx, cy, r, a1)
            if math.dist(cur, p0) > 1e-6:
                wp = wp.lineTo(*p0)
            wp = wp.threePointArc(pm, p1)
            cur = p1
    return wp.close()


SECTION_PLANE = dict(origin=(0, 0, 0), xDir=(0, 1, 0), normal=(1, 0, 0))     # section u -> Y, v -> Z


def section_solid(s, length):
    """A plain length of any UK section along +X from 0 (mm)."""
    plane = cq.Plane(**SECTION_PLANE)
    k = s["kind"]
    if k in ("I", "U", "L"):
        return _wire(cq.Workplane(plane), _outline_path(s)).extrude(length)
    if k == "M":
        t = s["t"]
        outer = cq.Workplane(plane).center(0, s["h"] / 2).rect(s["b"], s["h"]).extrude(length).edges("|X").fillet(s["ro"])
        inner = cq.Workplane(plane).center(0, s["h"] / 2).rect(s["b"] - 2 * t, s["h"] - 2 * t).extrude(length)
        if s["ri"] > 0:
            inner = inner.edges("|X").fillet(s["ri"])
        return outer.cut(inner)
    if k == "RO":
        d, t = s["d"], s["t"]
        return cq.Workplane(plane).center(0, d / 2).circle(d / 2).circle(d / 2 - t).extrude(length)
    raise ValueError(k)


# ======================================================================= a part with its holes and cuts
def _band(s, pl):
    """How far a cut-out on this plate goes through the steel: (lo, hi) mm, across the plate
    (Y for upright plates, Z for flat ones) - the plate, plus the root radius next to it."""
    k = s["kind"]
    if k == "L":
        t, r1 = s["t"], s["r1"]
        return (s["b"] / 2 - t - r1, s["b"] / 2 + 1) if not pl["flat"] else (-1, t + r1)
    r = s["r"]
    if pl["flat"]:
        return (pl["v0"] - r, pl["v1"] + 1) if pl["face"] == "o" else (pl["v0"] - 1, pl["v1"] + r)
    return (pl["u0"] - r, pl["u1"] + r) if k == "I" else (pl["u0"] - r, pl["u1"] + 1)


def _face_plane(s, pl, lo):
    """Workplane for drawing in a plate's own face coordinates (x along, y across like NC1)."""
    if pl["flat"]:   # local x = X, local y = Y; extrude +Z from lo
        return cq.Plane(origin=(0, 0, lo), xDir=(1, 0, 0), normal=(0, 0, 1))
    return cq.Plane(origin=(0, lo, 0), xDir=(1, 0, 0), normal=(0, 1, 0))     # local y = -Z: see _to_local


def _to_local(s, pl, x, y):
    """NC1 face point -> 2D point on _face_plane."""
    if pl["flat"]:
        return (x, S.face_to_section(s, pl["face"], y))
    return (x, -y)


def _prism(s, pl, pts, band):
    lo, hi = band
    local = [_to_local(s, pl, x, y) for x, y in pts]
    return cq.Workplane(_face_plane(s, pl, lo)).polyline(local).close().extrude(hi - lo)


def part_solid(part):
    """A part as one solid (mm, along +X from 0): the section with every notch, end cut, hole,
    slot and opening cut out exactly as the NC1 file / part editor says."""
    s = part.sec
    L = part.length
    body = section_solid(s, L)
    by_face = {p["face"]: p for p in S.plates(s)}
    for pl in S.plates(s):
        outline = part.face_outline(pl["face"])
        W = S.face_width(s, pl["face"])
        xs, ys = [p[0] for p in outline], [p[1] for p in outline]
        if len(outline) == 4 and min(xs) > -0.01 and max(xs) < L + 0.01 and min(ys) > -0.01 and max(ys) < W + 0.01 \
                and abs(max(xs) - min(xs) - L) < 0.01:
            continue                                                    # plain square ends: nothing to cut
        band = _band(s, pl)
        everything = _prism(s, pl, [(-2, -2), (L + 2, -2), (L + 2, W + 2), (-2, W + 2)], band)
        body = body.cut(everything.cut(_prism(s, pl, outline, band)))
    for hole in part.holes:
        pl = by_face.get(part.hole_face(hole))
        if pl is None:
            continue
        lo, hi = (pl["v0"] - 1, pl["v1"] + 1) if pl["flat"] else (pl["u0"] - 1, pl["u1"] + 1)
        cx, cy = _to_local(s, pl, hole["x"], hole["y"])
        wp = cq.Workplane(_face_plane(s, pl, lo)).center(cx, cy)
        slot = hole.get("slot") or 0
        if slot > hole["d"]:
            ang = hole.get("angle", 0) or 0
            wp = wp.slot2D(slot, hole["d"], -ang if pl["flat"] else -ang)
        else:
            wp = wp.circle(hole["d"] / 2)
        body = body.cut(wp.extrude(hi - lo))
    for item in part.inner:
        pl = by_face.get(part.norm_face(item["face"]))
        if pl is not None:
            lo, hi = (pl["v0"] - 1, pl["v1"] + 1) if pl["flat"] else (pl["u0"] - 1, pl["u1"] + 1)
            body = body.cut(_prism(s, pl, item["points"], (lo, hi)))
    return body


def export_parts(paths, out_dir=None):
    """One STEP file per NC1 part. Returns the files written."""
    need_cadquery()
    from beamcell import nc1
    out_dir = out_dir or os.path.join(CAD_DIR, "parts")
    os.makedirs(out_dir, exist_ok=True)
    written = []
    for path in paths:
        with open(path) as fh:
            part, _ = nc1.read(fh.read(), os.path.basename(path))
        if part.sec["kind"] not in S.CUTTABLE:
            continue
        out = os.path.join(out_dir, f"{part.mark}.step")
        cq.exporters.export(part_solid(part), out)
        written.append(out)
    return written


# ======================================================================= building blocks
class Model:
    """Named, labelled, coloured solids (mm). Becomes a STEP assembly and a GLB for the 3D view.
    `group` puts a solid in a moving body (e.g. 'cutter.bridge'); static things have group None."""

    def __init__(self, name):
        self.name = name
        self.items = []            # (group, name, label, workplane/shape, colour)
        self.names = {}
        self.cuts = []             # aluminium extrusions to cut: (profile, length mm, what for)

    def add(self, name, label, shape, colour, group=None):
        n = self.names.get(name, 0)
        self.names[name] = n + 1
        self.items.append((group, f"{name}_{n + 1}" if n else name, label, shape, colour))
        return shape

    def box(self, name, label, colour, x0, x1, y0, y1, z0, z1, group=None):
        shape = cq.Workplane().box(x1 - x0, y1 - y0, z1 - z0, centered=False).translate((x0, y0, z0))
        return self.add(name, label, shape, colour, group)

    def cyl(self, name, label, colour, p0, p1, r, group=None, r1=None):
        p0, p1 = np.asarray(p0, float), np.asarray(p1, float)
        d = p1 - p0
        L = float(np.linalg.norm(d))
        if L < 1e-6:
            return None
        if r1 is None:
            solid = cq.Solid.makeCylinder(r, L, cq.Vector(*p0), cq.Vector(*(d / L)))
        else:
            solid = cq.Solid.makeCone(r, r1, L, cq.Vector(*p0), cq.Vector(*(d / L)))
        return self.add(name, label, cq.Workplane().add(solid), colour, group)

    def hollow(self, name, label, colour, w, h, t, p0, p1, group=None):
        """A real RHS / SHS (w x h x t, outer corner radius 2t, inner t) between two points on one axis.
        w is across in the first other axis (Y for X members, X for Z members), h in the second."""
        p0, p1 = np.asarray(p0, float), np.asarray(p1, float)
        axis = int(np.argmax(np.abs(p1 - p0)))
        L = float(abs(p1[axis] - p0[axis]))
        outer = cq.Workplane("XY").rect(w, h).extrude(L).edges("|Z").fillet(min(2 * t, w / 2 - 0.1, h / 2 - 0.1))
        inner = cq.Workplane("XY").rect(w - 2 * t, h - 2 * t).extrude(L).edges("|Z").fillet(max(t, 0.5))
        shape = outer.cut(inner)
        if axis == 0:
            shape = shape.rotate((0, 0, 0), (0, 1, 0), 90).rotate((0, 0, 0), (1, 0, 0), 90)   # Z -> X; w along Y, h along Z
        elif axis == 1:
            shape = shape.rotate((0, 0, 0), (1, 0, 0), -90)
        start = np.minimum(p0, p1)
        shape = shape.translate(tuple(start if axis == 2 else start))
        return self.add(name, label, shape, colour, group)

    def tube(self, name, label, colour, p0, p1, r, t, group=None):
        """A round tube (CHS / roller tube) of outside radius r and wall t."""
        p0, p1 = np.asarray(p0, float), np.asarray(p1, float)
        d = p1 - p0
        L = float(np.linalg.norm(d))
        u = cq.Vector(*(d / L))
        solid = cq.Solid.makeCylinder(r, L, cq.Vector(*p0), u).cut(cq.Solid.makeCylinder(r - t, L, cq.Vector(*p0), u))
        return self.add(name, label, cq.Workplane().add(solid), colour, group)

    def cable(self, name, label, colour, points, r, group=None):
        """A cable or hose along a route: straight runs with a rounded bend at every corner."""
        pts = [np.asarray(p, float) for p in points]
        shape = None
        for a, b in zip(pts, pts[1:]):
            L = float(np.linalg.norm(b - a))
            if L < 1e-6:
                continue
            seg = cq.Solid.makeCylinder(r, L, cq.Vector(*a), cq.Vector(*((b - a) / L)))
            shape = seg if shape is None else shape.fuse(seg)
        for p in pts[1:-1]:
            shape = shape.fuse(cq.Solid.makeSphere(r, cq.Vector(*p), angleDegrees1=-90, angleDegrees2=90))
        return self.add(name, label, cq.Workplane().add(shape), colour, group)

    def section(self, name, label, colour, title, length, at=(0, 0, 0), axis="x", group=None):
        """A length of a UK section: along X (lying like on the bed) or standing up (axis='z')."""
        solid = section_solid(S.get(title), length)
        if axis == "z":                                     # X -> Z, the section's v (up) -> -X
            solid = solid.rotate((0, 0, 0), (0, 1, 0), -90)
        return self.add(name, label, solid.translate(tuple(at)), colour, group)

    def extrusion(self, name, label, colour, size, p0, p1, group=None, use=None):
        """Aluminium T-slot extrusion (e.g. 20x40) between two points, drawn as its outer box
        with the four slots grooved along it."""
        a, b = size
        p0, p1 = np.asarray(p0, float), np.asarray(p1, float)
        d = p1 - p0
        L = float(np.linalg.norm(d))
        axis = int(np.argmax(np.abs(d)))
        dims = [0.0, 0.0, 0.0]
        dims[axis] = L
        others = [i for i in range(3) if i != axis]
        dims[others[0]], dims[others[1]] = a, b
        self.cuts.append((f"{min(a, b):.0f}x{max(a, b):.0f}", round(L), use or name.replace("_", " ")))
        lo = np.minimum(p0, p1).copy()
        lo[others[0]] -= a / 2
        lo[others[1]] -= b / 2
        shape = cq.Workplane().box(*dims, centered=False).translate(tuple(lo))
        # slots: 6 mm wide, 6 mm deep, centred on each 20 mm module of each face
        for k, (w_dim, other) in enumerate(((a, others[1]), (b, others[0]))):
            n = int(round(w_dim / 20))
            for i in range(n):
                for side in (0, 1):
                    sd = [0.0, 0.0, 0.0]
                    sd[axis] = L
                    sd[others[k]] = 6.0
                    sd[other] = 6.0
                    pos = lo.copy()
                    pos[others[k]] = lo[others[k]] + 10 + 20 * i - 3
                    pos[other] = lo[other] + (0 if side == 0 else (b if other == others[1] else a) - 6)
                    shape = shape.cut(cq.Workplane().box(*sd, centered=False).translate(tuple(pos)))
        return self.add(name, label, shape, colour, group)

    # ------------------------------------------------------------ output
    def assembly(self, scale=1.0, groups=None, merge=False):
        """cq.Assembly of the static solids (groups=None) or of the given moving bodies, each moving
        body a sub-assembly named after it ('cutter.link3' -> 'cutter_link3')."""
        assy = cq.Assembly(name=self.name)
        subs = {}
        items = self.items
        if merge and groups is None:
            # for the 3D view: every static solid with the same label and colour becomes one mesh (one draw call),
            # so hundreds of bolts, anchors and bearings don't slow the screen down. STEP keeps them separate.
            merged, order = {}, []
            for group, name, label, shape, colour in items:
                if group is not None:
                    continue
                key = (label, colour)
                if key not in merged:
                    merged[key] = [name, []]
                    order.append(key)
                vals = shape.vals() if hasattr(shape, "vals") else [shape]
                merged[key][1] += [v for v in vals if isinstance(v, cq.Shape)]
            items = [(None, merged[k][0], k[0], cq.Compound.makeCompound(merged[k][1]), k[1]) for k in order]
        for group, name, label, shape, colour in items:
            if (groups is None) != (group is None) or (groups is not None and group not in groups):
                continue
            obj = shape.val() if hasattr(shape, "val") else shape
            if hasattr(shape, "vals") and len(shape.vals()) > 1:
                obj = cq.Compound.makeCompound([v for v in shape.vals() if isinstance(v, cq.Shape)])
            if scale != 1.0:
                obj = obj.scale(scale)
            if group is None:
                assy.add(obj, name=name, color=cq.Color(*colour))
            else:
                subs.setdefault(group, cq.Assembly(name=group.replace(".", "_"))).add(obj, name=name, color=cq.Color(*colour))
        for group, sub in subs.items():                  # added complete: cq copies a sub-assembly when it's added
            assy.add(sub, name=group.replace(".", "_"))
        return assy

    def labels(self):
        return {name: label for _, name, label, _, _ in self.items}


# ======================================================================= the full-size cell
def _hand_rest(hand):
    side = [1, 0, 0] if hand.tool == "torch" else [-1, 0, 0]
    return hand.preference([0, 0, -1], side)[1]
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

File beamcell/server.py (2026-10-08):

"""
The web server: serves the app in web/ and a small JSON API. Python standard library only
(plus numpy), so it runs on the Jetson as it is.

    python3 -m beamcell.server            # then open http://localhost:8080
    python3 -m beamcell.server --port 8000 --camera 0

API (all JSON):
    GET  /api/info                  machine, UK code tables, section families, system info
    GET  /api/sections              every section in the UK library (sizes)
    GET  /api/section?title=...     one section with its exact outline and plates
    GET  /api/examples              example NC1 files;  GET /api/examples/<file> -> parsed part
    POST /api/nc1                   {filename, text} -> part + import report + checks
    POST /api/nc1/export            {part} -> NC1 text
    POST /api/part                  {part} -> checks, face outlines, weight
    POST /api/nest                  {parts, stock_length} -> bars
    GET  /api/recovery              a job that was interrupted (stop, power cut): where it was; POST /api/recovery-discard
    POST /api/machine-size          {length_m: 12 | 20} -> change the machine's length (remembered in config/machine.json)
    POST /api/plan                  {parts, stock_length, bar} -> motion plan for one bar
    POST /api/manual/check          {section, length, cuts} -> pieces + UK checks for a manual cut
    POST /api/manual/plan           {section, length, cuts} -> motion plan for the manual cuts
    GET  /api/prototype             the 1:10 prototype: shopping list with part numbers + every position
    GET  /api/cad                   the CAD files in cad/;  GET /cad/<file> downloads one
    POST /api/cad/part              {part} -> STEP solid of the part (needs CadQuery: a PC, not the Jetson)
    GET  /api/jobs, GET/POST /api/jobs/<name>   saved jobs (jobs/ folder); POST /api/jobs-delete/<name> deletes one
    GET  /api/sensors               every sensor (camera 1 + 2, bar, torch, Handler, safety), and every stop's decisions
    POST /api/sensors/measure       {section, length[, measured]} -> the bar check (BS EN 10034 tolerances)
    GET  /api/plasma[?process=o2]   the plasma cut chart; POST /api/plasma/settings {feature, thickness[, d]}
    GET  /api/plasma/presets        saved plasma settings (plasma_settings/ folder); GET /api/plasma/presets/<name> one;
                                    POST /api/plasma/presets {settings} saves; POST /api/plasma/presets-delete/<name>
    GET  /api/plasma/start?section=&process=&grade=   new settings for a beam, from the cut chart
    GET  /api/reports               problem reports (reports/ folder, one per stop); GET /api/reports/<id> one;
                                    POST /api/reports-sent/<id>, /api/reports-delete/<id>, /api/reports-clear
    GET  /api/history, POST /api/history-delete/<id>, POST /api/history-clear   jobs that ran (jobs/history.json)
    GET  /api/camera, POST /api/camera, GET /camera.mjpg   camera + person detection
    GET  /api/camera/devices        the cameras Linux can see
    GET  /api/safety                safety controller status
    POST /api/safety/<action>       tick (watchdog + hold-to-run), estop, release, reset, start,
                                    stop, finished, mode, checklist, input, job {name}, clear-job
    GET  /api/situation             plain-English "what's happening" (no AI)
    POST /api/assistant             {question} -> optional AI advisor (advisory only)
    GET  /api/config                settings from config/cell.toml and any problems in them
"""
import argparse
import json
import mimetypes
import os
import re
import socket
import sys
import time
import traceback
import uuid
from http.server import BaseHTTPRequestHandler, ThreadingHTTPServer
from urllib.parse import parse_qs, unquote, urlparse

from beamcell import assistant, collisions, history, machine, manual, nc1, plasma, plasma_presets, recovery, reports, sensors, \
    sections as S, uk_codes as UK
from beamcell.config import CONFIG, problems as config_problems
from beamcell.gpio_inputs import GpioInputs
from beamcell.parts import Part, nest_all
from beamcell.planner import Plan
from beamcell.safety import SafetyController
from beamcell.vision import Vision

ROOT = os.path.dirname(os.path.dirname(os.path.abspath(__file__)))
WEB = os.path.join(ROOT, "web")
EXAMPLES = os.path.join(ROOT, "examples", "nc1")
JOBS = os.path.join(ROOT, "jobs")
VISION = Vision(os.path.join(ROOT, "models"))
VISION.configure({"zones": {"warning": CONFIG["camera"]["warning_zone"], "danger": CONFIG["camera"]["danger_zone"],
                            "bed": CONFIG["camera"]["bed_zone"]}})
SAFETY = SafetyController(vision=VISION)
GPIO = GpioInputs(SAFETY, CONFIG["gpio"])


def _report_stop(code, text):
    """A stop during a job: save where it is (to carry on later) and a problem report for the developer."""
    recovery.save(SAFETY.job, SAFETY.playback, "STOPPED", last_stop=f"{time.strftime('%H:%M:%S')} {text}", force=True)
    st = SAFETY.status()
    cam = VISION.status()
    reports.record(code, text, {
        "job": st.get("job"), "playback": dict(SAFETY.playback),
        "safety": {k: st.get(k) for k in ("state", "mode", "stop_category", "inputs", "input_source", "checklist_ok")} |
                  {"latched": [x["code"] for x in st.get("latched", [])]},
        "events": st.get("events", [])[:40],
        "camera": {"state": "on" if cam["enabled"] else "off", "detector": cam["detector"], "fps": cam["fps"],
                   "people": cam["people"], "in_danger": cam["in_danger"], "message": cam["message"]},
    })


PLANS = {}                                  # plan id -> the bar it was planned for (the bar check at Start needs it)


def _bar_check(job):
    bar = PLANS.get(job.get("plan_id"))
    if bar is None:
        return {"ok": False, "checks": [], "problems": [{"what": "Plan", "text": "this job's plan is no longer on the machine (the app was restarted)",
                                                        "fix": "Press Plan again, then Start."}]}
    return sensors.job_check(bar, resume=job.get("resume"))


SAFETY.bar_checker = _bar_check
SAFETY.on_stop = _report_stop
SAFETY.on_reset = reports.close_incident


def system_info():
    info = {"python": sys.version.split()[0], "host": socket.gethostname()}
    try:
        with open("/proc/device-tree/model") as fh:
            info["board"] = fh.read().strip("\x00\n")
    except OSError:
        info["board"] = "not a Jetson"
    try:
        mem = {}
        with open("/proc/meminfo") as fh:
            for line in fh:
                k, v = line.split(":")
                mem[k] = int(v.split()[0]) // 1024
        info["memory_mb"] = {"total": mem.get("MemTotal"), "available": mem.get("MemAvailable"),
                             "swap_free": mem.get("SwapFree")}
    except OSError:
        pass
    info.update(VISION.capabilities())
    return info
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

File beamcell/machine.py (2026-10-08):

"""
The gantry cell: a 12 m or 20 m long (LENGTHS, set_length), 3 m wide work area with two overhead hands.

            Y (width, 3 m)
            ^
            |   outfeed table (finished parts)      y = +0.85
            |   ===================================
            |   steel beam on the bed               y = -0.50
            +-------------------------------------> X (length, 12 m work area)

Each hand = one gantry BRIDGE running along X on the shared rails,
            a CARRIAGE running along the bridge in Y,
            a COLUMN that drops down in Z,
            and a 6-axis ARM hanging upside down under the column.
That is 3 gantry axes + 6 arm joints = 9 axes per hand.

Both bridges share the same rails, so they can never pass each other:
the Handler always stays on the low-X side, the Cutter on the high-X side,
and their bridges must stay at least MIN_GAP apart.
"""
import json
import os

import numpy as np

from beamcell.arm import Arm, wrap
from beamcell.config import CONFIG, ROOT

LENGTHS = (12.0, 20.0)         # the machine sizes the software knows (work length along X, m)
CHOICE_FILE = os.path.join(ROOT, "config", "machine.json")   # the size picked on the screen (kept on this machine)

# ---- cell layout (metres) ----
WORK_LENGTH = 12.0             # usable length along X
WIDTH = 3.0                    # rails are 3 m apart (Y from -1.5 to +1.5)
RAIL_Z = 3.4                   # height of the rails / bridges
BED_Z = 0.9                    # top of the beam supports (beam sits on this)
BEAM_Y = -0.5                  # centre line of the beam on the bed
OUTFEED_Y = 0.85               # where finished parts are put down
X_LIMITS = (-1.3, WORK_LENGTH + 1.3)   # rails run past both ends for parking
Y_LIMITS = (-1.4, 1.4)
Z_LIMITS = (1.25, 3.0)         # height of the arm base (bottom of the column)
Z_SAFE = 3.0                   # column fully up: safe to travel anywhere
MIN_GAP = 1.0                  # closest the two bridges may get (centre to centre)

# ---- what holds the steel up: every loose piece must rest on one of these (gravity) ----
G = 9.81                       # m/s^2
ROLLER_R = 0.05                # bed rollers, top of each roller = BED_Z
ROLLER_X = [0.5 + i for i in range(12)]          # every 1 m; the bar ends overhang, so the trim falls clear
OUTFEED_DECK = (-0.3, WORK_LENGTH + 0.3, OUTFEED_Y - 0.45, OUTFEED_Y + 0.45)   # x0, x1, y0, y1; top = BED_Z
SCRAP_TRAY_Z = 0.10            # floor of the scrap tray under the bed (offcuts fall onto it)


def set_length(length_m):
    """Make the cell 12 m or 20 m long. Everything that depends on the length follows: the rails, the
    parking places, the rollers, the outfeed table (the planner, the bar check and the 3D view read them)."""
    global WORK_LENGTH, X_LIMITS, ROLLER_X, OUTFEED_DECK
    length_m = float(length_m)
    if length_m not in LENGTHS:
        raise ValueError(f"machine length must be one of {', '.join(f'{x:g} m' for x in LENGTHS)}")
    WORK_LENGTH = length_m
    X_LIMITS = (-1.3, WORK_LENGTH + 1.3)
    ROLLER_X = [0.5 + i for i in range(int(round(WORK_LENGTH)))]
    OUTFEED_DECK = (-0.3, WORK_LENGTH + 0.3, OUTFEED_Y - 0.45, OUTFEED_Y + 0.45)
    return WORK_LENGTH


def saved_length():
    """The size chosen on the screen (config/machine.json), else config/cell.toml [machine] length_m."""
    try:
        with open(CHOICE_FILE) as fh:
            return float(json.load(fh)["length_m"])
    except (OSError, ValueError, KeyError):
        return float(CONFIG.get("machine", {}).get("length_m", 12))


def choose_length(length_m):
    """Change the size and remember it for the next start."""
    set_length(length_m)
    os.makedirs(os.path.dirname(CHOICE_FILE), exist_ok=True)
    with open(CHOICE_FILE, "w") as fh:
        json.dump({"length_m": WORK_LENGTH}, fh)
    return WORK_LENGTH


def supported_on_rollers(x0, x1):
    """Does a loose piece lying from x0 to x1 (m) stay on the bed? It needs a roller on each side
    of its middle - one roller alone would let it tip over and fall into the scrap tray."""
    mid = (x0 + x1) / 2
    return any(x0 <= r < mid for r in ROLLER_X) and any(mid <= r <= x1 for r in ROLLER_X)


def fall_time(height):
    """Seconds for a piece to drop `height` metres (from rest, no air drag)."""
    return (2 * max(height, 0.0) / G) ** 0.5


# Gantry axis speeds (m/s) and acceleration (m/s^2)
AXIS_SPEED = np.array([1.0, 0.8, 0.5])
AXIS_ACCEL = 1.0

# Starting guesses (degrees, J1 is added on top) that lead to "elbow up" poses
# for an upside-down arm. Found once by a search over many starting poses.
ELBOW_UP_SEEDS = [(0, -90, -60, 0, 90, 0), (0, -90, -120, 90, 90, 0), (0, -90, -60, -90, -90, 0),
                  (0, -30, -120, 0, -90, 0), (0, -90, -60, 90, -90, 0)]
_PREFS = {}   # remembered comfortable poses, shared by every plan

# Arm mounted upside down: base X stays X, Y and Z flip. (This matrix is its own inverse.)
FLIP = np.diag([1.0, -1.0, -1.0])
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

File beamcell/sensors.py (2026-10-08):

"""
Every sensor the cell has, or will have. A sensor that isn't fitted yet is SIMULATED: it answers
like the real one would, so the rest of the software (planning, safety, the screens) is ready
for the day it is wired in. Each one says what it is for, where it goes and what to buy.

The bar check (measure_bar) is what real beam lines do before cutting. A rolled beam is never
exactly its catalogue size, or exactly where it was put:
  - BS EN 10034 lets an I/H section be a few mm deeper or wider, out of square, and bowed by up
    to 0.1-0.3 % of its length (18 mm over 12 m for a UB 305),
  - the crane never puts the bar down at exactly x = 0.
So the machine finds the bar's ends and measures its real profile, then shifts every cut to the
real steel. Production lines do it with a laser scanner on the robot (Ficep NOZOMI), a measuring
sensor on the torch (Voortman V808) or a measuring stand (Lincoln Electric PythonX); the torch can
also touch the steel ("ohmic touch sensing").
"""
import hashlib

from beamcell import sections as S
from beamcell.config import CONFIG
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

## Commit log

2026-10-03 Robot arm learning project: simulator, exercises, Arduino digital twin, teach/replay, IK
2026-10-03 Test IK fallback headless and add test_ik_target.py
    The solve() fallback in ik_target.py passes: 300 random target jumps,
    0 failures, 0 base flips, worst error 0.10 mm. The old 740 mm error and
    -174 deg flip cases are fixed. Update CLAUDE.md status.
2026-10-03 Remove unused preview image and encoder test sketch
2026-10-03 Add GitHub Actions CI for headless tests and Arduino sketches
    Runs on every push: py_compile, a smoke test that each window script
    loads headless, exercises 8/8, the IK test, and compiles the Arduino
    sketches for the UNO. test_ik_target.py now exits non-zero on failure.
2026-10-03 Add gantry cell: 12 m beam cutting with two robot hands
    A simulated structural-steel cell: overhead gantry over a 12 m x 3 m
    work area, two bridges on shared rails, each with carriage, drop column
    and an upside-down 6-axis arm (9 axes per hand).
    - Cutter (plasma): holes and slots in top flange and web, copes, and
    full-profile cut to length incl. 45 deg bottom-flange cuts from both
    sides.
    - Handler (magnet): grips each part before it is cut free, then
    carries it to the outfeed rack while the Cutter moves on.
    - Planner keeps the bridges >= 1 m apart, uses elbow-up arm poses and
    safe approach/retract paths; check.py replays the plan for arm vs
    steel collisions.
    - gantry_cell.py: clic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
    [arm.py, machine.py, planner.py]
2026-10-03 Add Jetson hardware, storage and software specs for cloud sessions
2026-10-03 Rebuild as Beam Cell: UK beam cutting cell web app with NC1 import
    Replace the learning lessons, Arduino code and matplotlib gantry with a
    full prototype of a 12 m structural steel cutting cell:
    - beamcell/sections.py + data: 993 UK sections (BS 4-1 UB/UC/UBP/PFC,
    BS EN 10056-1 angles, BS EN 10210/10219 hollow) with exact outlines
    incl. root/toe radii (area x density matches table mass)
    - beamcell/uk_codes.py, parts.py: BS EN 1090-2 hole sizes, EC3-1-8 UK NA
    edge/end/spacing checks, notch rules (Blue Book N x n, SCI P358),
    per-face outlines like DSTV, nesting with trim/shared cuts/gaps
    - beamcell/nc1.py: DSTV NC1 reader/writer (ST, BO, AK, IK) for Tekla
    - planner: I, channel and ang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
    [arm.py, collisions.py, machine.py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]
2026-10-03 Add safety system: latching E-stops, interlocks, modes, config, doctor, advisor
    - beamcell/safety.py: safety controller with latching E-stop (cat 0) and
    protective stops (cat 1), separate Reset and Start, pre-start checklist,
    Auto / Manual (250 mm/s hold-to-run) / Maintenance (LOTO) modes,
    heartbeat and camera watchdogs, fume extraction interlock, camera
    warning (slow) and danger (stop) zones, event log, BS EN ISO 13855 distance
    - beamcell/gpio_inputs.py: optional fail-safe wired E-stop, gate, curtain
    and reset inputs on the Jetson header
    - config/cell.toml + beamcell/config.py: one settings file, validated
    - beamcell/doctor.py: system check and setup plan (--save writes docs/SYSTE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
    [assistant.py, config.py, doctor.py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]
2026-10-03 Browser test: wait for the machine state instead of fixed delays
    Passes with the CPU throttled 6x (SLOW=6), like the slow CI runner.
2026-10-04 Holes where the drawing says, cut in order along the bar
    - examples rebuilt by tools/make_examples.py: web bolt groups centred on the
    web left below any notch, no stray flange holes; T1 likewise
    - planner: square the start first, then holes along the bar one bolt group
    at a time (top hole first), then the cut-off - no jumping back and forth
    - parts editor: new bolt groups centre on the clear web; 'centre' button per hole
    - tests for both
2026-10-04 Gravity: every piece rests on something
    - machine: rollers every metre (bar ends overhang), outfeed table deck at bed
    height, scrap tray under the bed; supported_on_rollers() and fall_time()
    - planner: offcuts fall straight down into the tray (t_land from g); a short
    remnant that can't span two rollers falls too; heavy parts too short to
    stay on the rollers are flagged
    - 3D: bed rails, legs and bearing blocks, scrap tray, grating outfeed table;
    offcuts drop with g and tip over flat if short and tall
    - tests: carried parts land on the table, loose pieces on two rollers or in the tray
    [assistant.py, machine.py, planner.py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]
2026-10-04 Manual cutting: holes, cuts and notches by hand or by clicking the steel
    - beamcell/manual.py: a bar plus the operator's cuts -> pieces (carried to
    the outfeed table, short ones fall into the scrap tray, the rest stays on
    the rollers), the same UK checks, mitred cuts as one shared line, notches
    get their own start cut
    - planner: placements can be 'keep' or 'scrap' (no Handler, gravity drop)
    - server: POST /api/manual/check and /api/manual/plan
    - web: 'Manual cut' switch on the Machine tab, cut list, click on the web or
    top flange in 3D to add a hole or a cut, red markers, live check; plans
    and runs under the same safety rules
    - tests: python (pieces, mitres, notches, rules) and bro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
    [manual.py, planner.py, server.py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]
2026-10-04 Real CAD: STEP solids of the cell, the 1:5 prototype and every part
    - beamcell/cad.py (CadQuery, runs on a PC): UK sections with true arcs; each
    NC1 part as one solid with its holes, slots, notches and end cuts (volume
    checked against the section mass); the full cell with named, labelled
    solids; each hand's bridge, carriage, mast and arm links modelled in their
    own frames; the 1:5 desktop prototype from bought parts with a cut list
    - cad/: beam_cell.step, prototype_1to5.step, parts/*.step, cut list, parts list
    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
    [A1.step, B1.step, B2.step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]
2026-10-04 Prototype shopping list and build guide; docs for manual cut, CAD, gravity
    - docs/PROTOTYPE.md: the 1:5 working prototype - what it does (pen instead
    of a torch, SO-101 arms, FluidNC controller) and why, hard-wired E-stop and
    safety relay wiring, build stages, the full shopping list (~£1,900) with
    UK suppliers and checked prices
    - docs/prototype_bom.csv: the list as a spreadsheet; a test keeps its
    extrusion metres in step with the CAD cut list
    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
    [prototype_bom.csv]
2026-10-04 Hold-to-run stops the instant you let go; 3D view adapts on slow computers
    - Manual mode: releasing "Hold to move" stops motion in the browser at once
    instead of waiting for the server's next answer (BS EN ISO 10218 enabling
    device). Found by running the browser test on a 12x slower CPU.
    - 3D view: if frames take over 120 ms it drops shadows, then resolution, so
    the page (and its safety heartbeat) stays responsive - matters on the Jetson
    - browser test: says which stop is latched when a step fails; passes at 1x
    and with the CPU throttled 12x
2026-10-04 Camera auto-detect and clear camera errors; rename to Steel Beam Cutting Cell
    - camera: 'auto' finds a USB camera (V4L2, MJPG, warm-up) then the Jetson CSI
    camera; spots a CSI node or a USB info node picked by mistake; tolerates
    dropped frames; every failure says why (no /dev/video, video group, OpenCV
    without GStreamer, ribbon cable)
    - Camera tab lists the cameras Linux sees; doctor does too
    - project renamed: Steel Beam Cutting Cell by Ravi Mahadeva; README, paths,
    start-at-boot service; developer notes in docs/DEVELOPMENT.md
    [config.py, doctor.py, server.py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]
2026-10-04 Jobs and safety work together: a checklist for every job, Job finished window, delete jobs
    - safety controller knows the loaded job: no Start without one; every job needs
    its own pre-start checklist (cleared when a job finishes, or when a job that
    ran is swapped for another); a job can't be swapped or cleared while running;
    new first checklist item: outfeed table and scrap tray cleared
    - 'Job finished' window: next bar, run again, clear the job, or keep it - with
    the steps to make the cell safe before the next job
    - Clear job on the Machine tab; delete saved jobs on the Parts tab
    - Safety tab and 'What's happening' say which job the checklist is for
    - the end of a job is noticed even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
    [assistant.py, config.py, safety.py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]
2026-10-04 Prototype shopping list as a PDF (tick boxes, stage totals, cut list)
    tools/make_bom_pdf.py builds docs/Prototype_Shopping_List.pdf from docs/prototype_bom.csv
    and the CAD cut list.
2026-10-04 Shopping list: a buy link for every item and the total cost up front
    [prototype_bom.csv]
2026-10-04 Prototype assembly: part numbers and positions everywhere
    - every shopping-list line has a part number (P01-P47); every solid in the
    prototype CAD is named by part and position (P11-2 = 2nd NEMA 17), also in
    cad/prototype_positions.csv with what it is and where it goes
    - Prototype tab: 3D assembly with part-number balloons (or every position),
    click a part or row to see it, where it goes and the buy link; explode slider
    - docs/Prototype_Assembly.pdf: assembly drawing with title block - general
    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
    [prototype_1to5.step, prototype_bom.csv, prototype_parts.csv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]
2026-10-04 1:10 desk-top prototype: smaller frame, MeArm arms on PCA9685, new BOM (~£1,100), CAD and assembly drawing
    [prototype_1to10.step, prototype_1to5.step, prototype_bom.csv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]
2026-10-04 Job history with delete, gantry plates and column base plates in the right place, 30 s promo video
    - Job history (jobs/history.json): every job that finishes (or is cleared part-way) is recorded;
    Job history & saved jobs window on the Machine tab with Delete per entry, Delete all, and
    Open / Delete for saved jobs; the Job finished window links to it
    - A job reaching its end is finished even if it was paused right at the end
    - Prototype: mini V-wheel plates clamp the rails from both sides on eccentric spacers; the
    carriage plate stands on the side of the bridge and the Z axis no longer passes through it
    - Full-size cell: columns centred on their base plates; crane wheels stand on the cr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
    [beam_cell.step, prototype_1to10.step, prototype_bom.csv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]
2026-10-05 Sensors, bar check, hazard decisions and plasma settings
    - Sensors tab: two cameras (cell overview, torch close-up), bar-present photo-eye, datum laser,
    profile scanner, encoders, torch touch-off, arc voltage, breakaway, magnet current, load cell,
    battery backup, light curtain, area scanner, fume flow, fire detector - simulated until fitted
    - Bar check before cutting (BS EN 10034 tolerances): start offset, length, depth, width,
    out-of-square, bow - shown under every plan
    - New stops with fixed decisions for each hand: object on the bed, load slipping, torch collision,
    fire; category 2 stops keep the magnet holding; Simulate buttons on the Sensors and Safety tabs
    - Plasma cut chart (O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
    [beam_cell.step, prototype_1to10.step, prototype_bom.csv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]
2026-10-05 Delete one part or one bar; a finished bar leaves the Machine tab
    - Parts & NC1: a delete button on every part (instead of only Clear all)
    - Machine tab: a delete button on every bar - takes just that bar's parts out of the job
    - When a bar finishes, its parts are taken off the job (they're in the job history), the rest
    re-nest, and no finished job stays loaded; the Job finished window offers the next bar,
    cutting the same bar again, or deleting the rest of the job
2026-10-06 YOLO on the GPU with TensorRT; people and objects; bed zone
    - beamcell/trt_runner.py: runs a TensorRT engine on the Jetson's GPU (CUDA through ctypes - no
    PyTorch or pycuda needed)
    - vision.py: best detector first (GPU engine, then CPU ONNX, then HOG); finds objects as well as
    people; a third camera zone, the bed: objects lying there are listed, and stop the machine when
    safety.camera_object_stop = true (off by default)
    - tools/make_trt_engine.sh builds the engine on the Jetson; doctor checks TensorRT and engines
    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
2026-10-06 Camera: try a YOLO model once when it loads and fall back to HOG with a clear message if this OpenCV can't run it; docs: the Jetson's OpenCV 4.6 can't run YOLOv8/11 on the CPU - use the GPU engine
2026-10-06 Job history: record every stop during a job (E-stop, gate, camera, load slip, Stop button) and show 'clean' or the stops; the history file can't be listed, saved over or deleted as a saved job
    Claude-Session: https://claude.ai/code/session_017XfkmjAHDgHnLwW9VEeVrZ
    [history.py, safety.py, server.py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]
2026-10-06 Plasma tab: try settings, save the ones that cut well (one file per beam in plasma_settings/), and the plan uses them; problem reports for the developer after every stop (reports/, send as a GitHub i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
    - beamcell/plasma_presets.py: web and flange settings per beam, checked, saved, listed, applied to each cut
    - planner: uses saved settings instead of the cut chart when a job names them; plan shows which
    - Machine tab: Plasma list above Plan picks the beam's saved settings automatically; saved jobs remember them
    - beamcell/reports.py: one report per stop incident (stops until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
    [config.py, planner.py, plasma_presets.py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]
2026-10-06 Bar check at Start: after the safety checks the bar is measured and checked against the job - section, web and flange thickness, length the job needs, every hole on the real steel, holes already in t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
    - sensors.job_check(); BS EN 10034 thickness tolerances; simulated wrong bars (Sensors tab: Bar on the bed)
    - safety: Start runs the bar check once per bar, only when everything else allows the machine to move
    - server keeps each plan's bar so Start can check it; the plan shows a preview
    - edge / end distance messages show one decimal (26.4, not 26)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
    [parts.py, safety.py, sensors.py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]
2026-10-06 The bar check you can see: before any cut the Cutter drives along the bar with the torch camera and profile laser (red laser fan in 3D), then says what it measured; fix: 'Run again' skipped the bar c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
    - planner: a measuring pass at the start of every plan (plan.scan)
    - the job line shows the bar check: measured at Start / matches / doesn't match
    - 'Run these cuts again' now registers the plan, so the new bar is measured
    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
    [planner.py, test_presets_reports.py]
2026-10-08 Bar check measures the web as well as the flange: a second pass along the web from the side; the section is identified from depth, flange width, web and flange thickness; 'wrong web' simulation
    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
    [planner.py, sensors.py, test_plasma_sensors.py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]
2026-10-08 Machine size: 12 m or 20 m long (3 m wide), chosen on the Machine tab and remembered; planner, bar check, stock lengths (15/18/20 m), manual cuts and the 3D model follow; CAD for both sizes (beam_cel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
    [beam_cell.step, beam_cell_20m.step]
2026-10-08 Realistic cables and the bar-measured window
    - energy chains along both runways (fold as the bridges travel) and across each bridge to its carriage
    - dress packs: torch lead + gas hose down the Cutter's mast and arm, power cable to the magnet
    - CAD: control cabinet with lockable isolator, plasma power source + gas console + gas supply,
    floor trunking, risers up the columns, chain trays on the runways (12 m and 20 m models)
    - after the two measuring passes a window shows the program (NC1 job or manual cut) next to the bar on
    the cutting area: web depth and thickness, flange width and thickness, bow, length, verdict
    - remove a node_modules link committed by mistake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
    [beam_cell.step, beam_cell_20m.step]
2026-10-08 Real model: Tekla IFC of the steelwork (12 m and 20 m) and realistic 3D parts
    A - Tekla:
    - beamcell/ifc_export.py: IFC2X3 of all fabricated steel - runways UB457*191*67, columns UC254*254*73 with cap
    and base plates, crane rails, X-bracing, roller bed RHS/SHS, outfeed table, tray brackets, end stop; S355,
    UK Tekla profile names, marks, assemblies, property set; cut lists (CSV) with masses (12 m 6.6 t, 20 m 9.7 t)
    - docs/TEKLA.md: import into Tekla, marks, what is not designed (connections, end-frame stability, foundations)
    C - 3D parts as the real thing:
    - roller bed: RHS 120x80x5 rails, SHS 80x80x5 legs, foot plates and anchors, 101.6x3.6 roller tubes on 25 mm
    shafts in UCP205 pillow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
    [beam_cell.step, beam_cell_20m.step, beam_cell_steel_12m.csv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]
2026-10-08 Carry on after a stop or a power cut: progress saved to disk every second and at every stop; on restart a window says when, why and where it stopped and what is done; carry on re-plans the same job, 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
    [recovery.py, safety.py, sensors.py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]
2026-10-08 Every device wired: field cable tray on the fence with drops to light curtain, area scanners, photo-eyes, datum laser, gate switch and flame detector; stack light, desk E-stop, screen and camera to t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
    [beam_cell.step, beam_cell_20m.step]
2026-10-08 Loading and unloading without entering the cell: infeed cross-transfer rack and driven infeed conveyor (pop-up end stop, bridging rollers), outfeed chain cross-transfer every 1 m through the back fen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
    [beam_cell.step]
2026-10-08 Faster 3D: identical static parts merged into one mesh each for the screen (652 -> 127 draw calls; STEP keeps every part), arm dress packs rebuilt at most 10 times a second - the hold-to-run test is 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
    [beam_cell.step]
2026-10-09 Welcome screen (BEAM CELL, designed and built by Ravi Mahadeva) while the machine loads; arm cables no longer jump: clamped straight down the mast and along the arm, updated smoothly every frame in t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
